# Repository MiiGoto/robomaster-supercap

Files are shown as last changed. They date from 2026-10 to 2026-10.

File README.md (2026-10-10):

# Firmware implementation — 2026-10-08

Current: Rev A STM32G474RET6 firmware source implemented; default SAFE_MONITOR_ONLY. Host logic tests and ARM builds are recorded in [docs/firmware_validation.md](docs/firmware_validation.md). No flash, option-byte write, real PWM/contact actuation or energizing was performed. Hardware/CAD is unchanged. Calibration, control gains, timing, BQ physical behavior and power limits require bench measurement and human review before first flash/energizing.

Current guides: [firmware architecture](docs/firmware_architecture.md), [operation](docs/supercap_user_guide.md), [commissioning](docs/firmware_commissioning.md), [CAN protocol](docs/can_protocol.md), [tuning](docs/control_tuning.md), [flash setup](docs/firmware_flash_setup.md).

## Historical records (preserved)

# PCB routing complete — 2026-10-07

**Current: Prototype Rev A CAD routing complete.** KiCad10.0.6の正式PCBでnative未接続0、全DRC0 errors/0 warnings、schematic parity0、ERC0 errors/0 warningsを確認した。全331ネット／1524 net-assigned pad recordsの物理接続と、設計manifestの1478 pad/net assignmentsを照合済み。これはCAD接続・規則検証であり、製造リリース、通電許可、120 W性能、競技適合の承認ではない。

一般銅箔間隔0.20 mm、承認済み39 ICの同一部品内Pad/Pad0.15 mmを維持した。新たなDRC除外・No ERC・規則緩和はない。未コミットの`.kicad_pro`設定展開は保持し、functional commitに含めない。詳細は[配線完了記録](docs/pcb_routing_completion.md)を現在の情報源とする。以下は過去時点の記録として保存する。

## Historical records (preserved)

# Routing checkpoint — 2026-10-04

**Routing incomplete.** 保存したPCBは電力7ネットの全パッド接続と、局所GND/一部信号配線を追加したcheckpoint。native未接続 **610本**（239 nets）、寸法・間隔DRC **0 errors/0 warnings**、schematic parity0。元の935本から325本を解消したが、配線完成/製造/通電/性能保証は意味しない。

現在の結果と残りを[配線作業記録](docs/pcb_routing_completion.md)で確認する。以下は以前の経緯を含む。

# Clearance approval update — 2026-10-04

39対象ICの内部fine-pitchパッド間0.15 mmをユーザー承認に基づき許容し、その他の銅箔間隔は0.20 mm以上を維持した。DRCの寸法・間隔違反0/0、未接続935本。[検証記録](docs/pcb_rev_a_validation.md)を現状として優先する。以下は変更前の経緯を含む。

# PCB engineering authorized — 2026-10-04

ユーザーがsurge・OC遮断時間・fuse/接触器協調・熱・放電時間の実測前にPCB配置/配線へ進むことを明示承認した。[現行PCB記録](docs/pcb_rev_a.md)を優先する。未実測の項目はPrototype Assumptionとして保持し、製造/通電/性能保証にはしない。以下の「PCB未承認/開始しない」は過去時点の記録として残す。

## Historical records (preserved)

# Prototype Rev A — 2026-10-04 delegated decisions

ユーザーの委任に基づき、セル監視RAM設定・exact passive選定・外部ベンチ遮断アセンブリ・保護/熱/放電検証基準を[現行選定書](docs/rev_a_design_freeze.md)へ確定した。選定はPrototype Assumption、実測検証は未実施。平均cap電流の初期上限9.5 A、OC約12 A、目標遮断0.5 µs、各link bulk6×470 µF、precharge timeout3 s。12 A/120 Wは後続の検証目標として保持。PCB placement/通電は開始しない。以下の2026-10-03以前の未選定表示は経緯記録であり、この選定書が優先する。

# Prototype Rev A — current status

2026-10-03 JST。**Current: Prototype Rev A schematic only.** Task2 architectureはユーザー採用承認済み。実機条件未確認は[Prototype envelope](docs/prototype_rev_a_envelope.md)に明示した **ASSUMPTION — MUST VERIFY ON PROTOTYPE** として隔離し、詳細electrical schematicを作成した。部品/保護閾値はprototype候補で性能保証ではない。[現行review](docs/rev_a_schematic_review.md)と[pinout](docs/pinout.md)が現在の設計記録。PCB placement/routing、firmware、通電、120W使用許可、競技適合、Task4開始は未承認。以下の旧status/approval pending/skeleton-only記述はhistorical recordであり現在statusではない。

[Validation record](docs/rev_a_validation.md): ERC0/0 baseline; current counts in validation record. External assembly and cell-monitor RAM profile are selected; hardware programming/qualification remain unperformed.

## Historical records (preserved)

# Task 4 current status — placement gate未通過

2026-10-03 JST。Task 3 base428ad10を保持。重大TBDと詳細回路未実装のため添付Task 4 §1に従いplacement/outline/footprint/routingは行わない。[独立review](docs/task4_review.md)が現在status、[PCB方針](docs/task4_pcb_strategy.md)は提案、[検査結果](docs/task4_baseline.md)は既存skeleton限定。Task 5へ進まない。以下は過去Task記録。

---

# Task 3 current status

2026-10-03 JST。Task 2案はユーザー採用承認済み。実bus/surge・peak継続/間隔・ambient/coolingは未確定（ユーザー回答：不明）。承認範囲と詳細回路gateは[Task 3 review gate](docs/task3_review_gate.md)を優先する。Task 3は候補評価まで進行中、詳細回路未実装。以下のTask 2承認待ち表示は承認範囲についてhistorical record。

---

# robomaster-supercap — Task 2

2026 RMUL用energy bufferの設計検討。英雄・歩兵・哨兵の競技assistが対象、EngineerはS5搭載許可対象外。Task1成果を保ち、Task2 architecture proposal・simulation・9-page KiCad conceptを追加。完成/検証済み回路ではない。

- [Requirements/status](requirements.md)
- [Architecture and 11 modes](docs/architecture.md)
- [Evidence and selected proposals](docs/task2_decisions.md)
- [Calculation results](simulation/results.md)
- [Safety](docs/safety.md) / [FMEA](docs/fmea.md)

第一案は9S 50F、4-switch bidirectional buck-boost、G474RE/LQFP64、signed high-side shunts、independent fault latch。全選定案はAssumptionとしてhuman review待ち、robot実bus/power/thermalはTBD。stored energyはOFF後も残る。
Roadmap: Task1完了→Task2 reviewable proposal→人間承認→別途Task3 component selection。mainへ自動mergeしない。詳細回路・routing・firmware・hardware testingなし。第三者PDF等は公開対象外、引用linkと出典のみ。

---

## Task 1 record (historical; Task 2 above takes precedence)

# robomaster-supercap

RoboMaster向けスーパーキャパシタ電源システムの要求・安全設計と開発基盤。
robot busの余剰energyを蓄え、必要時にassistし、状態監視とCAN通信を行う。

## Architecture

Robot Power Bus ⇄ Input Protection ⇄ Bidirectional Power Converter ⇄ Supercapacitor Bank。
MCUはbus/bank voltage、current、temperature、faultを監視する。独立保護がgate enableを拒否できる構成を要求する。
競技用の公式管理モジュール・検査経路を含む実接続は適用規則確認後に決める。

## Repository structure

```text
README.md / AGENTS.md / PROJECT_CONTEXT.md
requirements.md / references.md
hardware/kicad/        block-level project skeleton
firmware/controller/  future firmware requirements
simulation/           future model scope
docs/                 architecture, comparison, safety, FMEA, bringup
test/                 verification plan and publication audit
```

## Safety notice

蓄積energyは電源OFF後も残る。短絡・cell過電圧・逆流・熱暴走・connector arcを設計要件として扱う。
このrepositoryは通電可能な完成回路、製造データ、検証済みシステムを提供しない。
KiCad ERCが通っても、部品・netがないskeletonの安全性や動作は証明しない。

## Current status

Task 1文書とKiCad skeleton。詳細power stage、PCB layout、firmware、prototypeは未着手。
Confirmed / Assumption / TBDはPROJECT_CONTEXTとrequirementsに明示。
環境確認は [environment](docs/environment.md)、調査は [comparison](docs/reference_comparison.md)。

## Reference policy

外部設計は設計意図を比較し、[references.md](references.md)へ記録する。
外部回路図・PCB・PDF・画像・コードは取り込まない。ライセンスの衝突・不明点も記録する。
本プロジェクトの公開ライセンス選択はTBD。PUBLICであることだけで再利用許諾とはしない。

## Roadmap

1. Task 1: environment / repository / research / requirements / safety / KiCad skeleton。
2. 人間レビュー: 競技適用、robot仕様、capacitor候補、限界値、topology。
3. 承認後の別Task: 詳細回路、独立保護の検証、制御設計。
4. その後: PCB / firmware / 段階的bringup / fault injection / robot統合。

Task 2は自動開始しない。

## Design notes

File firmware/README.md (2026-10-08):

# Firmware implementation — 2026-10-08

Current: Rev A STM32G474RET6 firmware source implemented; default SAFE_MONITOR_ONLY. Host logic tests and ARM builds are recorded in docs/firmware_validation.md. No flash, option-byte write, real PWM/contact actuation or energizing was performed. Hardware/CAD is unchanged. Calibration, control gains, timing, BQ physical behavior and power limits require bench measurement and human review before first flash/energizing.

Current guides: [firmware architecture](../docs/firmware_architecture.md), [operation](../docs/supercap_user_guide.md), [commissioning](../docs/firmware_commissioning.md), [CAN protocol](../docs/can_protocol.md), [tuning](../docs/control_tuning.md), [flash setup](../docs/firmware_flash_setup.md).

## Historical records (preserved)

# PCB routing complete — 2026-10-07

**Current: Prototype Rev A CAD routing complete.** KiCad10.0.6の正式PCBでnative未接続0、全DRC0 errors/0 warnings、schematic parity0、ERC0 errors/0 warningsを確認した。全331ネット／1524 net-assigned pad recordsの物理接続と、設計manifestの1478 pad/net assignmentsを照合済み。これはCAD接続・規則検証であり、製造リリース、通電許可、120 W性能、競技適合の承認ではない。

一般銅箔間隔0.20 mm、承認済み39 ICの同一部品内Pad/Pad0.15 mmを維持した。新たなDRC除外・No ERC・規則緩和はない。未コミットの`.kicad_pro`設定展開は保持し、functional commitに含めない。詳細は[配線完了記録](../docs/pcb_routing_completion.md)を現在の情報源とする。以下は過去時点の記録として保存する。

## Historical records (preserved)

# PCB engineering authorized — 2026-10-04

ユーザーがsurge・OC遮断時間・fuse/接触器協調・熱・放電時間の実測前にPCB配置/配線へ進むことを明示承認した。[現行PCB記録](../docs/pcb_rev_a.md)を優先する。未実測の項目はPrototype Assumptionとして保持し、製造/通電/性能保証にはしない。以下の「PCB未承認/開始しない」は過去時点の記録として残す。

## Historical records (preserved)

# Prototype Rev A — 2026-10-04 delegated decisions

ユーザーの委任に基づき、セル監視RAM設定・exact passive選定・外部ベンチ遮断アセンブリ・保護/熱/放電検証基準を[現行選定書](../docs/rev_a_design_freeze.md)へ確定した。選定はPrototype Assumption、実測検証は未実施。平均cap電流の初期上限9.5 A、OC約12 A、目標遮断0.5 µs、各link bulk6×470 µF、precharge timeout3 s。12 A/120 Wは後続の検証目標として保持。PCB placement/通電は開始しない。以下の2026-10-03以前の未選定表示は経緯記録であり、この選定書が優先する。

# Firmware status — Prototype Rev A

No firmware implementation. Adopted STM32G474RE/LQFP64 pin allocation and default-off protections are in [pinout](../docs/pinout.md) and [schematic review](../docs/rev_a_schematic_review.md). Future work: HRTIM timing/ADC synchronization, BQ supercap provisioning/readback, watchdog health/CAN lease, control loops, precharge/dump/contact interlocks and fault state machine. BOOT0/NRST options and cell monitor profile must be reviewed before any energizing. Hardware latch protection is not optional. Historical firmware requirements remain in [controller README](controller/README.md).

Cell monitor RAM profile now exists in config/bq76942_rev_a.json;check_cell_profile.py is offline arithmetic only. Firmware has not been implemented or flashed.

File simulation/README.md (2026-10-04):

# Prototype Rev A — 2026-10-04 delegated decisions

ユーザーの委任に基づき、セル監視RAM設定・exact passive選定・外部ベンチ遮断アセンブリ・保護/熱/放電検証基準を[現行選定書](../docs/rev_a_design_freeze.md)へ確定した。選定はPrototype Assumption、実測検証は未実施。平均cap電流の初期上限9.5 A、OC約12 A、目標遮断0.5 µs、各link bulk6×470 µF、precharge timeout3 s。12 A/120 Wは後続の検証目標として保持。PCB placement/通電は開始しない。以下の2026-10-03以前の未選定表示は経緯記録であり、この選定書が優先する。

# Task 2 calculation model

Python standard library only。power_budget.py冒頭のBank/BUS_V/power変数で3 scenariosを変更可能。C/F、V、Ω、A、W、J、sのSI単位。ηはconverterのみ、ESRを別計算。

```text
python simulation/power_budget.py --write-report
python -m unittest discover -s test -p "test_*.py"
```

results.mdは公開用の自作計算結果。runtimeは電流clippingを含みpeak ratingではない。aux/leakage/temperature/loop/transient/thermalモデルを含まず楽観値。SPICE/firmware実装ではない。

---

## Task 1 record (historical; Task 2 above takes precedence)

# Simulation scope

Task 1ではモデル実装なし。将来の検証: bus/cap電圧の上下関係、ESR損失、cellばらつき、precharge、shutdown放電、fault時のbody-diode電流経路。
control-loop compensation、switching frequency最適化は別Task。

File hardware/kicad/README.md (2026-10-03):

# Task 2 same-project update

robomaster_supercap.kicad_proを継続使用。root UUIDと既存sheet UUIDを維持しPRECHARGEを追加、9 concept pages。各sheetにblock interfaceの説明を更新。POWER_STAGEは四switch概念textのみでMOSFET/driver/L部品・netsなし、electrical connectivity未実装。PCB/project設定はTask1から変更なし。
ERC成功はhierarchy読み込み確認のみ。部品ratings/pin/機能/safety検証ではない。

---

## Task 1 record (historical; Task 2 above takes precedence)

# KiCad skeleton

Open `robomaster_supercap.kicad_pro` with KiCad 10.0.6。
rootと7 hierarchy pages: CONTROLLER / POWER_INPUT / SUPERCAP_BANK / POWER_STAGE / SENSING / CAN / SAFETY。
説明textのみ。部品、pin、electrical nets、MOSFET、driver、inductor、connector定格の実装なし。
PCBは空のplaceholder。outline、footprint、track、zoneなし。厚さ等のKiCad defaultは承認済み製造仕様ではない。
ERCはparser/hierarchy確認であり電気安全や配線の検証ではない。空boardのDRCはoutlineがない等の未実装結果をexpected limitationとして記録する。
generatorは新規targetのみ作成し既存fileがあれば拒否。通常編集はKiCadで行い、generator再実行で上書きしない。

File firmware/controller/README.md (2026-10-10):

# Firmware implementation — 2026-10-08

Current: Rev A STM32G474RET6 firmware source implemented; default SAFE_MONITOR_ONLY. Host logic tests and ARM builds are recorded in [docs/firmware_validation.md](../../docs/firmware_validation.md). No flash, option-byte write, real PWM/contact actuation or energizing was performed. Hardware/CAD is unchanged. Calibration, control gains, timing, BQ physical behavior and power limits require bench measurement and human review before first flash/energizing.

Current guides: [firmware architecture](../../docs/firmware_architecture.md), [operation](../../docs/supercap_user_guide.md), [commissioning](../../docs/firmware_commissioning.md), [CAN protocol](../../docs/can_protocol.md), [tuning](../../docs/control_tuning.md), [flash setup](../../docs/firmware_flash_setup.md).

## Build and tests

Project-authored source: Core (HAL adapters), App (portable logic), config (reviewed defaults/profile), tests (host emulator). External unmodified HAL/device/CMSIS versions and licenses: [Drivers/README.md](Drivers/README.md). No automatic downloads, installs, flash or hardware operations exist in build targets.

Host (Linux/WSL GCC or another supported C11 GCC/Clang installation):

```sh
cmake -S firmware/controller -B build/firmware-host
cmake --build build/firmware-host -j 4
ctest --test-dir build/firmware-host --output-on-failure
python -B firmware/controller/tools/generate_bq_profile.py --check
python -B firmware/controller/tools/test_profile.py
```

ARM (set external paths to the pinned sources; Ninja optional):

```sh
cmake -S firmware/controller -B build/firmware-arm -G Ninja \
  -DCMAKE_TOOLCHAIN_FILE=cmake/arm-gcc.cmake \
  -DARM_TOOLCHAIN_BIN=/path/to/arm-tools/bin \
  -DHAL_ROOT=/path/to/hal -DDEVICE_ROOT=/path/to/device -DCMSIS_ROOT=/path/to/cmsis \
  -DFW_MODE=SAFE_MONITOR_ONLY
cmake --build build/firmware-arm -j 4
```

Windows: use `tools/build_windows.ps1` with explicit `-CMake`, `-Ninja`, `-ArmTools`, `-HalRoot`, `-DeviceRoot`, `-CmsisRoot` paths. It uses temporary ASCII junctions because the tested Ninja cannot resolve the Unicode checkout path. It never removes/replaces an existing alias and never moves the checkout. `-Mode` defaults SAFE_MONITOR_ONLY; select a new `-AliasRoot` if an existing alias belongs to another checkout. Output is ELF/HEX/map under the alias build directory, not programmed into a board.

Project code uses -Wall/-Wextra/-Werror; vendor code is separately compiled without -Werror. Host builds execute all three modes with mocked hardware permissions; those test fixtures do not change production default permissions. Optional host sanitizer configuration (tested WSL non-PIE executable, add `-DCMAKE_EXE_LINKER_FLAGS=-no-pie`): `-DCMAKE_C_FLAGS="-fsanitize=address,undefined -fno-omit-frame-pointer -fno-pie"`.

Native connectivity audit: export a local-only KiCad S-expression netlist, then `python -B firmware/controller/tools/check_hardware_contract.py path/to/export.net`. Do not commit native exports containing absolute local paths. The audit checks47 U11 physical assignments plus ADC/AF sentinels; it is not a hardware timing test.

## Historical records (preserved)

# Prototype Rev A — 2026-10-04 delegated decisions

ユーザーの委任に基づき、セル監視RAM設定・exact passive選定・外部ベンチ遮断アセンブリ・保護/熱/放電検証基準を[現行選定書](../../docs/rev_a_design_freeze.md)へ確定した。選定はPrototype Assumption、実測検証は未実施。平均cap電流の初期上限9.5 A、OC約12 A、目標遮断0.5 µs、各link bulk6×470 µF、precharge timeout3 s。12 A/120 Wは後続の検証目標として保持。PCB placement/通電は開始しない。以下の2026-10-03以前の未選定表示は経緯記録であり、この選定書が優先する。

# Prototype Rev A — current status

2026-10-03 JST。**Current: Prototype Rev A schematic only.** Task2 architectureはユーザー採用承認済み。実機条件未確認は[Prototype envelope](../../docs/prototype_rev_a_envelope.md)に明示した **ASSUMPTION — MUST VERIFY ON PROTOTYPE** として隔離し、詳細electrical schematicを作成した。部品/保護閾値はprototype候補で性能保証ではない。[現行review](../../docs/rev_a_schematic_review.md)と[pinout](../../docs/pinout.md)が現在の設計記録。PCB placement/routing、firmware、通電、120W使用許可、競技適合、Task4開始は未承認。以下の旧status/approval pending/skeleton-only記述はhistorical recordであり現在statusではない。

## Historical records (preserved)

# Controller firmware placeholder

実装なし。STM32G4 / F334を比較中。型番・pinout・toolchain projectはTBD。
将来: boot self-test → precharge → charge/standby/assist → fault/shutdown。
PWM同期ADC、current loop、hardware fault inputs、watchdog、CAN timeout、telemetry、calibration管理を分離する。
起動・reset・crashでenable OFF。ISR時間予算と通信処理の分離を検証する。
SWD halt時のPWM継続も危険として扱う。デバッグで保護を無効化しない。

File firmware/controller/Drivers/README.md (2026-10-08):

# External STM32 dependencies

No vendor code is copied into this public repository. Project-authored code is in `Core/`, `App/`, `config/`, `tests/` and `tools/`. No CubeMX-generated files are claimed.

Build-tested source dependencies (unmodified, kept in ignored local storage):

| Dependency | Pinned version / commit | License | CMake setting |
|---|---|---|---|
| [ST G4 HAL](https://github.com/STMicroelectronics/stm32g4xx-hal-driver/tree/v1.2.5) |v1.2.5 / d69997c6dcdc2d672afae31fee03713fb033c4a8|BSD-3-Clause in LICENSE.md|HAL_ROOT|
| [ST G4 CMSIS device](https://github.com/STMicroelectronics/cmsis-device-g4/tree/v1.2.4)|v1.2.4 / f4ee399953e3b5c437788526e93b10efa5fad4fa|Apache-2.0|DEVICE_ROOT|
| [Arm CMSIS core](https://github.com/ARM-software/CMSIS_5/tree/5.9.0)|5.9.0 / 2b7495b8535bdcb306dac29b9ded4cfb679d7e5c|Apache-2.0|CMSIS_ROOT|

An installed STM32CubeG4 package may supply the same directories, but its exact revision must be recorded and rebuilt/reviewed. `CMSIS_ROOT/CMSIS/Core/Include` is the standalone CMSIS layout; for a Cube package point to its corresponding root layout or adjust the include path explicitly. Dependencies are not fetched by CMake. Toolchain installation, board connection and flashing are never build actions.

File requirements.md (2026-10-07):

# PCB routing complete — 2026-10-07

**Current: Prototype Rev A CAD routing complete.** KiCad10.0.6の正式PCBでnative未接続0、全DRC0 errors/0 warnings、schematic parity0、ERC0 errors/0 warningsを確認した。全331ネット／1524 net-assigned pad recordsの物理接続と、設計manifestの1478 pad/net assignmentsを照合済み。これはCAD接続・規則検証であり、製造リリース、通電許可、120 W性能、競技適合の承認ではない。

一般銅箔間隔0.20 mm、承認済み39 ICの同一部品内Pad/Pad0.15 mmを維持した。新たなDRC除外・No ERC・規則緩和はない。未コミットの`.kicad_pro`設定展開は保持し、functional commitに含めない。詳細は[配線完了記録](docs/pcb_routing_completion.md)を現在の情報源とする。以下は過去時点の記録として保存する。

## Historical records (preserved)

# PCB engineering authorized — 2026-10-04

ユーザーがsurge・OC遮断時間・fuse/接触器協調・熱・放電時間の実測前にPCB配置/配線へ進むことを明示承認した。[現行PCB記録](docs/pcb_rev_a.md)を優先する。未実測の項目はPrototype Assumptionとして保持し、製造/通電/性能保証にはしない。以下の「PCB未承認/開始しない」は過去時点の記録として残す。

## Historical records (preserved)

# Prototype Rev A — 2026-10-04 delegated decisions

ユーザーの委任に基づき、セル監視RAM設定・exact passive選定・外部ベンチ遮断アセンブリ・保護/熱/放電検証基準を[現行選定書](docs/rev_a_design_freeze.md)へ確定した。選定はPrototype Assumption、実測検証は未実施。平均cap電流の初期上限9.5 A、OC約12 A、目標遮断0.5 µs、各link bulk6×470 µF、precharge timeout3 s。12 A/120 Wは後続の検証目標として保持。PCB placement/通電は開始しない。以下の2026-10-03以前の未選定表示は経緯記録であり、この選定書が優先する。

# Prototype Rev A — current status

2026-10-03 JST。**Current: Prototype Rev A schematic only.** Task2 architectureはユーザー採用承認済み。実機条件未確認は[Prototype envelope](docs/prototype_rev_a_envelope.md)に明示した **ASSUMPTION — MUST VERIFY ON PROTOTYPE** として隔離し、詳細electrical schematicを作成した。部品/保護閾値はprototype候補で性能保証ではない。[現行review](docs/rev_a_schematic_review.md)と[pinout](docs/pinout.md)が現在の設計記録。PCB placement/routing、firmware、通電、120W使用許可、競技適合、Task4開始は未承認。以下の旧status/approval pending/skeleton-only記述はhistorical recordであり現在statusではない。

## Rev A current requirements register

| Item | Current decision | Status |
|---|---|---|
| Rules |2026 RMUL,prior source editions;event supplement applicability remains open |Confirmed target / eligibility TBD|
| Bank |9S SCCV40B506SRB50F;Ceq5.5556F;rest12–22.05V;cell normal2.45V,COV2.530V |Adopted goals / Prototype selection|
| Bus |22–26V;surge investigation36V,measured VDS<=48V and reviewed SOA |Prototype Assumption / waveform TBD|
| Power/current |40W charge,80/120W assist requests;normal8A,initial peak-average9.5A;12A future goal |Adopted goals / capability TBD|
| Converter/MCU |Four-switch bidirectional buck-boost,G474RE/LQFP64,200kHz/22uH |Approved architecture / schematic only|
| Sensing/OC |Three3mR WSK2512 Kelvin,INA240 signed,INA293/TLV3202;cap/IL~12A;0.5us clearing required |Concrete schematic / actual response TBD|
| Cell monitor |BQ7694204,39-entryRAM profile,SPI CRC,9S0x02FF,COV/CUV,active-low-fault permits,host-only trim |Selected configuration / NOT programmed|
| Link/precharge |Each6×EEUFR1J471,100R HS25+AQZ202G,NO AEV bypass,3s timeout |Prototype selection / inrush test TBD|
| Discharge |10k bleed,100R HS25 dump/service;40min to1V target pluscell/rebound/energy checks |Procedure target / measured time TBD|
| External isolation |FourAEV14012,DDR-60L-12,MINI99758V fuses+0FHM holders;manual disconnect |Bench assembly selected / interruption coordination test TBD|

Confirmed means adopted target or checked fact; **does not mean demonstrated capability**. Full-power gates remain surge/regen/source impedance, duty, heat, OC clearing, residual energy and isolation fault capability. Current MCU allocation is docs/pinout.md, overriding historical spare-count/pin plans.

## Historical records (preserved)

# Task 4 current status — placement gate未通過

2026-10-03 JST。Task 3 base428ad10を保持。重大TBDと詳細回路未実装のため添付Task 4 §1に従いplacement/outline/footprint/routingは行わない。[独立review](docs/task4_review.md)が現在status、[PCB方針](docs/task4_pcb_strategy.md)は提案、[検査結果](docs/task4_baseline.md)は既存skeleton限定。Task 5へ進まない。以下は過去Task記録。

---

# Task 3 current status

2026-10-03 JST。Task 2案はユーザー採用承認済み。実bus/surge・peak継続/間隔・ambient/coolingは未確定（ユーザー回答：不明）。承認範囲と詳細回路gateは[Task 3 review gate](docs/task3_review_gate.md)を優先する。Task 3は候補評価まで進行中、詳細回路未実装。以下のTask 2承認待ち表示は承認範囲についてhistorical record。

---

# Task 2 requirements freeze — proposal, not construction approval

2026-10-03 JST。[採用理由・一次根拠・margin](docs/task2_decisions.md)、[計算](simulation/results.md)。Confirmedは実装完了を意味しない。Assumptionは人間レビュー待ち。

| Item | Current value / decision | Status | Remaining evidence |
|---|---|---|---|
| Ruleset | 2026 RMUL、哨兵/歩兵/英雄/エンジニアの要求 | Confirmed | 開催地/種目/補足TBD |
| Rule editions | RMUL CN V1.2.0 / 制作CN V1.3.0、公式RMULアーカイブ掲載最新版 | Confirmed | 会場答疑確認 |
| Eligibility | 底盤assist bankは英雄/歩兵/哨兵のみ、Engineer対象外(S5) | Confirmed | Engineerへの別用途は許可を推測しない |
| Supply maximum | 対象4種30 V、power management input22–26 V | Confirmed | converter実端のdroop/surgeはTBD |
| Vbus range | 計算22/24/26 V; 実operating min/nom/max | Assumption / TBD | battery型番、Chassis端波形、regen |
| Rule energy | nominal2000 J / measured2200 J | Confirmed | capacityはrated voltageで計算、実測検査 |
| Power constraint | 3V3 Hero/Sentry100 W, Infantry90/75 W; Infantry Match120 W | Confirmed | 種目/型選択、referee計測点の統合 |
| Cell count / product | SCCV40B506SRB、9S第一案; alternatives7S HV60 /4S HV100 | Assumption | thermal/stock/mount/人間承認 |
| Capacitance | cell50 F, Ceq5.5556 F nominal、tol−10/+30% | Assumption | 製品採用・実測・aging |
| Vcap range | useful12..22.05 V; nominal比較18 V; cell normal2.45 V | Assumption | 精度/balance/overshoot配賦の実証 |
| Cell rating | 選定候補datasheet2.7 V/cell, rated sum24.3 V | Confirmed (candidate) | normal定格と混同しない |
| Energy | A usable950.5625 J nominal; rated1640.25 J; +30%2132.325 J | Confirmed calculation under Assumption | 実効C/セル差/検査測定 |
| Charge current / power | bus input40 W scenario、normal cap clamp8 A | Assumption | 実charge max/TBD、referee負荷budget |
| Discharge current | normal8 A / peak12 A scenario; module peak/continuous15 A rule | Assumption / Confirmed rule | ripple/error/trip overshoot、熱定格TBD |
| Nominal / peak power | request80 /120 W、current/thermal/UVでderate | Assumption | 実max、peak duration、robot要求TBD |
| Converter | 4-switch non-inverting bidirectional synchronous buck-boost | Assumption selected proposal | 重なり電圧・制御・loss・人間承認 |
| Switching / L | 100–200 kHz; exploration11–22 µH, ΔI3 A p-p | Assumption | 全corner/duty/部品/温度で再算出 |
| MCU | STM32G474RE LQFP64; alternative G431RB | Assumption selected proposal | package AF conflict、errata、承認 |
| Current sensing | bus/cap high-side signed shunts + separate inductor sense | Assumption selected proposal | amplifier settling/共通故障/承認 |
| Voltage sensing | bus/bank ADC + differential per-cell monitor、独立OV | Confirmed requirement / Assumption method | tap protection/range/error |
| Temperature | MOSFET群/inductor/bank各代表1点NTC | Assumption | hotspot測定、thresholdsTBD |
| Balancing | IC-based switched passive、MCU非依存OV inhibit | Assumption selected proposal | IC/精度/損失/供給断時動作 |
| Precharge | resistor path + normally-OFF bypass、ΔV/current/time確認 | Assumption selected proposal | R/Clink/energy/start time/approval |
| Discharge | permanent bleed + controlled dump + service tool +独立表示 | Assumption selected proposal | Vsafe/Esafe/time/公式検査との共存TBD |
| Hardware protection | external OC/OV/latch/watchdog/kill、reset/float OFF | Confirmed requirement | clearing時間/回路/故障遮断能力TBD |
| CAN | telemetry使用、official module→CAN1、Classic CAN互換を想定 | Confirmed requirement / Assumption format | bitrate/ID/period/timeout/TBD |
| Mechanical / cooling | port1つ、検査lead≥100 mm、mount/冷却/絶縁 | Confirmed rule / TBD dimensions | robot envelope/thermal approval |
| Debug / test / firmware | SWD/UART、ADC同期、state machine、fault injection計画 | Confirmed requirement | implementation、試験は今回なし |
| Expansion | spare GPIO4、cell monitor interface | Assumption | pin plan/area |

Task 3へ進む前のhuman review: cell数/Vcap、max current/peak power、topology、MCU、sensing、prechargeと全power component定格。実robot仕様不明のため最終数値freezeではなく、証拠付きproposal freeze。Task 3自動開始禁止。

---

## Task 1 record (historical; Task 2 above takes precedence)

# Requirements register

2026-10-03 JST。Confirmed = 依頼から確定した要求または直接確認した資料の内容。
Assumption = 比較に使う仮定。TBD = 未決定。要求のConfirmedは実装・検証の完了を意味しない。

## Competition constraints: current applicability is TBD

公式 [Rules/Resources Hub](https://bbs.robomaster.com/wiki/20204847) と [downloads](https://www.robomaster.com/zh-CN/resource/download/competition) を確認。
取得できた一次資料は **2026制作規則 V1.3.0 (2026-02-09)**。以下はその版の内容としてConfirmed。
現在適用する最新版・大会・地域・robot種別はTBDであり、下記数値を本設計の確定限界値にしない。

[公式V1.3.0 PDF](https://bbs-web-static.robomaster.com/715e2519e5384666a5d13edda17c6b831770696773838/RoboMaster%202026%20%E6%9C%BA%E7%94%B2%E5%A4%A7%E5%B8%88%E9%AB%98%E6%A0%A1%E7%B3%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)

| 条項 / 印刷page | 確認した版での内容 | 本projectへの適用 |
|---|---|---|
| S5 / 14 | Hero / Infantry / Sentryのみ、各robot最大1組 | TBD |
| S6 / 14 | nominal energy合計 ≤2000 J、measured energy合計 ≤2200 J。nominal計算は耐圧と容量による1/2 C U² | TBD、動作電圧でnominalを過小評価しない |
| S7 / 14 | Chassisに接続し底盤powerに寄与しないcapacitorのnominal容量合計 ≤10 mF | TBD、通常bus decouplingも分類確認 |
| 3.12 / 97–98 | bankと自作power control boardの間に公式管理module、module CANはpower management CAN1へ | TBD、独自telemetry CANと混同しない |
| S184 / 98 | 公式moduleのXT30接口はpeak / continuousとも ≤15 A | TBD、bus側current限界とは同義でない |
| S185–189 / 98 | 検査時bankを満充電から1 V未満まで測定、検査lead ≥100 mm、moduleにアクセス可能、bank power接口は1つ | TBD、1 Vを一般のservice-safe閾値としない |

第三者indexにはV2.0.0制作規則(2026-06-26)とV2.2.0競技規則(2026-08-07)、2027先行資料への案内があった。
一次資料としての最新版取得・版照合はできず、第三者PDF linkは404。探索はここで停止した。
対象大会を決め、公式hubから最新版と補足を取得し、上表の変更差分・接続図・chassis power計測点を人間レビューする。
最大bus電圧・許容powerは今回一次資料で対象robotに対して確定できていない。過去の24 V / 240 W等を流用しない。

## Requirements

| ID | Category | Requirement | Status | Acceptance / next evidence |
|---|---|---|---|---|
| COMP-01 | Competition constraints | 大会・年・地域・robot種別・最新規則・裁判systemを特定 | TBD | 版/date/条項/適用範囲をレビュー署名 |
| COMP-02 | Competition constraints | 公式管理module・検査path・single bank接口を満たす | TBD | 適用図面と接続を照合 |
| IN-01 | Electrical input | bus min/nominal/max、surge、source impedance、regen吸収能力 | TBD | robot power仕様と測定 |
| IN-02 | Electrical input | reverse polarity、inrush、busへの逆流を制限 | Confirmed | approved limitsでfault test |
| OUT-01 | Electrical output | assist power/current/duration、ripple、response time | TBD | robot load profile / competition制約 |
| ES-01 | Energy storage | cell数/製品/C/ESR/voltage/usable energy/agingを決定 | TBD | maker datasheetとworst case計算 |
| ES-02 | Energy storage | series cell imbalanceを検出し弱いcellを保護 | Confirmed | bank正常でもcell OVならcharge inhibit |
| CHG-01 | Charge control | current/power/voltage上限を守りsoft startする | Confirmed | 上限値TBD、independent trip検証 |
| CHG-02 | Charge control | referee計測点でpower budgetを守る | TBD | power budget loss/delay余裕を承認 |
| DIS-01 | Discharge control | bus電圧、bank/cell UV、熱、currentからassistを制限 | Confirmed | approved envelope外はinhibit |
| DIS-02 | Discharge control | charge↔assistはzero-current確認を経由 | Confirmed | reversal transientを検証 |
| VS-01 | Voltage sensing | busとbankを測定、ADC open/short/saturation/stuck診断 | Confirmed | calibrated測定とfault injection |
| VS-02 | Voltage sensing | per-cell監視方式とindependent OV path | TBD | 共通原因故障をレビュー |
| CS-01 | Current sensing | signed bus/bank/inductor電流の必要測定点を決定 | TBD | topologyとloop帯域から選択 |
| CS-02 | Current sensing | calibrationと独立fast overcurrent trip | Confirmed | sensor故障でも危険電流を止める |
| TS-01 | Temperature sensing | MOSFET/inductor/bankのriskから測定点選定 | Confirmed | hotspot熱測定、断線診断 |
| TS-02 | Temperature sensing | sensor数、derating/trip温度と応答 | TBD | datasheetとthermal model |
| COM-01 | Communication | CANによるmode/fault/voltage/current/energy/temp telemetry | Confirmed | protocol/ID/bitrate/periodはTBD |
| COM-02 | Communication | timeout、bus-off、stale commandはassist/chargeを無効化 | Confirmed | CAN lossと復帰時再arm検証 |
| SAF-01 | Safety | float/reset/crash/aux lossのdefault enable OFF | Confirmed | MCU不要のhardware inhibit確認 |
| SAF-02 | Safety | MOSFET短絡でもenergy fault pathを遮断/制限 | Confirmed | PWM OFFだけで合格しない |
| SAF-03 | Safety | OV/OC/UV/thermal、precharge timeout、reverse current保護 | Confirmed | thresholds / trip latency TBD |
| SAF-04 | Safety | shutdown後の放電、独立電圧確認、再上昇確認 | Confirmed | safe voltage/energy/time TBD |
| MECH-01 | Mechanical | vibration/impact、cell retention、絶縁、touch/arc防護 | Confirmed | enclosure/interfaceレビュー |
| MECH-02 | Mechanical | size/mass、mount、connector、serviceアクセス | TBD | robot envelopeと規則 |
| COOL-01 | Cooling | ESR/semiconductor/inductor/PCB損失の熱経路確保 | Confirmed | ambient/airflow/limits TBD |
| DBG-01 | Debug | SWD/UARTとfault log、halt時に安全停止 | Confirmed | debugger halt fault test |
| TEST-01 | Testability | sense/fault/enable測定点、current-limited初期試験 | Confirmed | bringup checklist |
| FW-01 | Firmware | 明示state machine、watchdog、latched fault、再arm | Confirmed | implementationは別Task |
| FW-02 | Firmware | ADC/PWM同期、ISR予算、calibration integrity | Confirmed | timing / checksum試験 |
| EXP-01 | Future expansion | balancing・telemetry拡張余地を比較 | Assumption | pin/area/cost予算承認 |

## Values requiring human approval

maximum bus voltage、capacitor maximum voltage、cell count、charge/discharge current、output power、topology、MOSFET/inductor/fuse/connector定格は全てTBD。
安全要求の存在は確定していても、数値・回路実現・検証は未確定。

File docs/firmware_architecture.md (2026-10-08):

# Rev A firmware architecture — 2026-10-08

Project-authored C11, HAL peripheral adapters, no RTOS or runtime allocation. Hardware remains unchanged. Routing-complete base: `f38ec4f`. Board U11 pin/net assignments were read from the native KiCad netlist; PC5 REFEREE_PERMIT is additionally implemented. Exact package pins are in `pinout.md`; board GPIO grouping and ADC rank lists are in `Core/Src/board.c`.

## Ownership / scheduling

|Layer|Responsibility|
|---|---|
|External protection + HRTIM FLT1|Asynchronous inactive PWM before ISR; cannot be overridden by a command|
|ADC2 DMA ISR|Latest signed IL, independent software instantaneous guard, PI/duty update; no SPI/CAN/printf/heap|
|ADC1 DMA ISR|Publish latest six-channel scan; foreground conversion|
|Main loop|BQ SPI, conversion, supervisor, CAN parser/telemetry, UART, log, watchdog heartbeat|
|Board safety adapter|Second runtime output veto and default-safe GPIO; short critical sections publish ISR demand/snapshots|

HSI16 PLL gives170 MHz CPU/HRTIM; ADC42.5 MHz. HRTIM master period27200 at×32 gives200 kHz, A/B complementary outputs with provisional deadtime34 fDTG ticks, preload and inactive fault levels. ADC trigger compare6800 is adjustable. ADC1 ranks: CH1 BUS_V,CH2 CAP_V,CH6 TEMP_FET,CH7 TEMP_L,CH8 TEMP_BANK,CH9 BUS_RAW. ADC2 ranks: CH3 IL,CH17 BUS_I,CH13 CAP_I,CH5 CAP_RAW. HAL rank enums are explicit, not assumed arithmetically contiguous. ADC1 circular96 halfword buffer reduces callback rate; ADC2 circular8 halfwords supplies one four-channel frame per half/full callback. Buffers reside in contiguous SRAM, not CCM.

SPI2 mode0/CRC uses~664 kHz; USART2 115200/8N1 interrupt RX/TX; FDCAN1 Classic500 kbit/s. HRTIM timers/ADC triggers may run for sensing in SAFE, but PWM pins remain GPIO LOW and waveform output start is not reachable. Startup sets output latches LOW before configuring output modes. CS and CAN standby start HIGH. CAN standby later becomes LOW for diagnostics.

External heartbeat toggles PB1 only after a completed foreground iteration, about50 ms; IWDG timeout is~1 s nominal LSI. No timer perpetually feeds the watchdog while foreground is stalled. Reset cause is recorded; reset never resumes a power session. HardFault/error handlers stop requests and await watchdog reset. Debug halt is not a safe operating state.

## Allowed transitions

All states may enter FAULT_LATCHED on a fault. Other unlisted transitions are rejected.

|From|To|Gate / condition|
|---|---|---|
|BOOT_SAFE|MONITOR_INIT|All actuators OFF|
|MONITOR_INIT|SELF_TEST|Profile configured/readback, healthy measurements; timeout fails|
|SELF_TEST|DISARMED|Self-test PASS; never auto-ARM|
|DISARMED|PRECHARGE|Explicit ARM + reviewed mode/calibration/tuning/permissions|
|DISARMED|SELF_TEST / SERVICE|Explicit reviewed command/path; dump default forbidden|
|PRECHARGE|READY|BothlinkΔV<1 V stable, bypass settles, resistor paths removed within3 s|
|PRECHARGE|SHUTDOWN|DISARM/SHUTDOWN|
|READY / STANDBY|CHARGE / ASSIST / STANDBY / SHUTDOWN|Fresh command and hardware/sensor permissions|
|CHARGE / ASSIST|STANDBY / SHUTDOWN|No direct direction reversal|
|SHUTDOWN|DISARMED / COOLDOWN / SERVICE|Gate OFF first; bounded zero-current observation; outputs OFF|
|COOLDOWN / FAULT_LATCHED|SELF_TEST|Cause absent, cooled, explicit REARM; then fresh ARM|
|SERVICE|DISARMED|Explicit exit; meter confirmation independent of software|

`app_transition` checks graph legality; `app_command`, `app_live_faults` and `app_safe_outputs` apply permissions/limits. Reserved PRE/BYP/ISO feedbacks are diagnostic samples only; voltage/current/time are used for sequence acceptance. Requests are not measured contact positions.

## BQ7694204

`firmware/config/bq76942_rev_a.json` generates39 RAM entries through `tools/generate_bq_profile.py`; check mode detects stale data. CRC-8 SPI transport verifies replies/echoes with bounded retries, data-memory checksum/length and full readback. Startup confirms device0x7694, enters CONFIG_UPDATE, programs RAM, verifies every entry, exits configuration, observes measurements and periodic open-wire check, checks safety/FET permissions, and publishes MON_CONFIG_VALID last. No OTP or FET test commands exist. Manufacturing FET_EN is read before any conditional toggle, verified after; ALL_FETS_ON follows configuration/safety checks as the existing profile requires.

Logical cells0..8 map to physical channels1..8,10 (mask0x02FF), not channel9. DCHG/DDSG logical fault bits and their physical polarity must be tested with a cell simulator. COW_CHK reports a running open-wire check, not a separate proof that all taps passed. Startup observes a cycle and evaluates measurements/safety; actual tap-disconnect coverage requires bench verification. POR is sticky and not a reliable new-reset counter; mode/status, rotated readback and physical permission loss provide additional detection. BQ failure clears config validity and inhibits power; no blind automatic recovery.

Host balancing: converter OFF, valid cells, bank0–40 C, cells≥2.3 V, startΔ20 mV/stopΔ10 mV policy, one cell, ≤1 s pulse,250 ms settle then remeasure. Measurement validity/PD2 drop during a pulse/settle; this is permitted only in disarmed/service, never a powered session. Independent OV remains active; balancing is not protection.

## Control / faults / calibration

Inner signed IL PI has feedforward duty and anti-windup. Slow power-to-current supervisor applies cell/voltage/thermal/current/peak limits. Initial gains and assumed efficiency are unvalidated; current PI and measured power behavior need bench tuning. Software cap target9.5 A does not replace external~12 A OC. Fault timestamp, first state/sensor snapshot, additional bitmask and frozen64-entry RAM history are retained until reset. No high-frequency Flash logging.

Default calibration gains reflect actual divider/shunt/NTC loading but validity=false; version/CRC detects corruption, not measurement accuracy. Factory defaults plus explicit reviewed flags are used; no in-field flash storage/update. ISR owns its PI context; foreground publishes demands in short interrupt-masked sections, and ISR publishes raw samples/fault flags. Maximum IRQ cycles are tracked, with a secondary period-overrun guard. Timing, sampling and filter delay remain bench items.

Sources: [TI BQ76942 TRM SLUUBY1B](https://www.ti.com/lit/ug/sluuby1b/sluuby1b.pdf), [ST RM0440](https://www.st.com/resource/en/reference_manual/dm00355726.pdf), [ST HAL/LL UM2570](https://www.st.com/resource/en/user_manual/um2570-description-of-stm32g4-hal-and-lowlayer-drivers--stmicroelectronics.pdf). Vendor source versions/licenses are in `firmware/controller/Drivers/README.md`.

ALERT PC11 is polled to request immediate cause-register scanning; an ALERT level alone is not classified as a specific fault. Six reserved feedback levels and ALERT/referee/IRQ-cycle diagnostics are available on telemetry page12. SERVICE dump requires the same monitor/hardware permissions, freshness and a provisional40 min timeout; DISARM exits SERVICE.

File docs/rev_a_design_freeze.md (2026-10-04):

# PCB engineering authorized — 2026-10-04

ユーザーがsurge・OC遮断時間・fuse/接触器協調・熱・放電時間の実測前にPCB配置/配線へ進むことを明示承認した。[現行PCB記録](pcb_rev_a.md)を優先する。未実測の項目はPrototype Assumptionとして保持し、製造/通電/性能保証にはしない。以下の「PCB未承認/開始しない」は過去時点の記録として残す。

## Historical records (preserved)

# Prototype Rev A — delegated design selections

2026-10-04 JST. The user delegated the remaining IC settings, external assembly, exact passives/lands and validation targets. These engineering selections supersede earlier **selection awaiting human decision** entries. They do not constitute measured results, purchase authorization, a fabrication release or permission to energize. **ASSUMPTION — MUST VERIFY ON PROTOTYPE.** PCB placement remains outside this task.

## Selected envelope and acceptance criteria

| Item | Rev A decision | Acceptance / consequence |
|---|---|---|
| Bus |22–26 V,24 V nominal; startup inhibit outside range; no accepted regenerative mode |Record converter-terminal voltage and source impedance; no referee bypass |
| Surge |Investigate36 V upstream events; SMBJ28A is not a36 V clamp; its rated clamp is45.4 V at its specified test current |At actual prototype source/cable/transient energy, protected rail<=45.4 V,FET VDS peak<=48 V,VGS inside datasheet limits and SOA; no repetitive avalanche. A failed test requires clamp/source protection redesign,not a wider undocumented assumption |
| Bank |Nine KEMET SCCV40B506SRB,50 F/2.7 V each;normal cell ceiling2.45 V;bank rest12–22.05 V |Ceq5.5556 F;effective C/ESR,imbalance and actual current/temperature characterized; exact product choice is a prototype selection |
| Energy |Nominal ideal useful950.5625 J;max stored1755.73125 J with+30%C |Usable output is lower after ESR and converter loss;cell limits can reduce window |
| Power |40 W converter charge input;80 W nominal/120 W peak assist requests |Reserve actuator/aux power separately: planning charge-point total<=71 W;does not establish a rule allowance |
| Current |8 A normal average;initial cap average maximum9.5 A;12 A goal retained for later verified envelope |At12 V rest model delivers about87.98 W under9.5 A clamp;120 W remains a request,not a guaranteed output |
| OC |Cap and IL nominal11.991 A with35.7k/10k at3.288 V;bus about7.98 A with58.7k/10k |Provisional aggregate error allowance±7%;**required** complete clearing<=0.5 us for48 V/14.08 uH corner. Arithmetic peak14.535 A. This demanding requirement is unproved; if unattainable,redesign fast sense/kill or reduce threshold/current. No ADC polling substitute |
| Switching |200 kHz primary,180–200 kHz exploration;22 uH XAL1510-223MED |Verify L>=14.08 uH through15 A at temperature and ripple before using OC excursion calculation;deadtime/refresh remain waveform tuning parameters |
| Pulse |Initial design scenario1 s,minimum30 s repetition;software cap current9.5 A |Only after low-energy characterization;temperature and electrical limits override timer |
| Thermal |Calculation25°C;operating test envelope ambient<=40°C,open bench,no credited forced air |Software stop FET/L65°C,bank50°C;warnings60/45°C;hardware backup~69.5/53.7°C. Cooldown below50/40°C plus explicit rearm. Verify junction<100°C,winding<90°C,bank<55°C,connectors<60°C including sensor lag. These are design targets,not measured temperatures |
| Precharge |100 Ω±1% HS25 100R F and AQZ202G per link;normally-open AEV bypass |Each link2820 uF bulk plus ceramics;worst t95~1.03 s;3 s timeout,delta-V<1 V and plausible voltage progression before bypass. Not whole-bank resistor charging |
| Discharge |10kΩ1W permanent bleed;100Ω±1% HS25 switched dump and separate service tool |Worst+30%C ideal~37.61 min to1 V;selected test acceptance<=40 min. With auxiliary failure,use independent tool,not a timing claim |
| Service condition |Bank/both local links<1 V,every cell magnitude<0.5 V,total residual energy<4 J,2 min rebound observation |Verify with independent meter after source disconnect. LED dark and OFF do not prove this condition. Failure keeps service access inhibited |

Sources for engineering facts are the [manufacturer register/reference list](../references.md); [new calculations](../simulation/rev_a_limits_results.md) are original arithmetic. Design limits above are deliberately below cell2.7 V/MOSFET60 V absolute ratings;margin only becomes meaningful after error,ringing and heat are measured.

## Cell monitor configuration

The complete **39-entry RAM-only** selection is [bq76942_rev_a.json](../firmware/config/bq76942_rev_a.json), audited by [offline checker](../tools/check_cell_profile.py). It is not MCU firmware and has not been written to hardware. Use SPI CRC;REG1=3.3 V;9S mask0x02FF (cells1–8+10);COV code50=>2.530 V,CUV24=>1.2144 V;delay code1=>about10 ms;hysteresis101.2 mV. Enable COV/CUV and monitor internal OT80°C;all main current protections remain on independent external hardware because SRP/SRN are grounded.

DCHG/DDSG config0xA6 means **active-low fault,healthy-high permission**,REG1 high drive and pulldown. It is not active-high fault. CHG protection A0x18 and DSG protection A0xE4 follow TI's fast-output mapping guidance;other masks use internal OT. FET_CTRL_EN remains set for logical outputs,charge pump disabled and CP1 tied BAT per the low-side application note;FET_INIT_OFF forces initial permission off. Readback and cell-simulator fault tests precede MON_CONFIG_VALID/ARM. Disable SLEEP for predictable monitoring;repeat RAM provisioning after every reset. No OTP programming,blind FET_ENABLE toggle or FET test command is permitted by this profile.

Open-wire check interval1 s;test every tap disconnect at commissioning and log actual latency. Alarm pin active-low/open-drain with external REG1 pullup. TS pins are unused;external bank NTC hardware is the real bank thermal protection. PF/chemical-fuse engine is not enabled in this prototype profile;the existing external latched shutdown remains mandatory. Configuration mismatch,CRC failure,monitor power loss or failed tap test inhibits operation.

Host-only internal switched-passive balancing:one cell at a time,1 s maximum command,converter disabled,all readings valid,bank0–40°C,cells>=2.3 V,start difference20 mV,stop10 mV. Ten source-side1kΩ1W resistors physically at electrodes plus ten onboard1kΩ1W input resistors protect the tap harness. A single source resistor at24.3 V dissipates at most0.591 W in the simplified short model. This arrangement allows only slow trim (~0.6 mA ignoring switch resistance),not correction during full40 W charge. Large imbalance stops charge and requires separate low-current commissioning;empty-bank startup is not the normal mode. Measurement/open-wire/balancing settling through2kΩ per tap must be tested;do not infer protection from bank voltage alone.

Primary sources: [BQ76942 TRM](https://www.ti.com/lit/ug/sluuby1b/sluuby1b.pdf), [low-side output configuration](https://www.ti.com/lit/an/sluaa84a/sluaa84a.pdf), [TI fast-output mapping FAQ](https://e2e.ti.com/support/power-management-group/power-management/f/power-management-forum/1237508/faq-bq76952-do-the-dchg-and-ddsg-signals-on-the-bq769x2-follow-th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).

## External bench assembly / power / fuses

Four Panasonic AEV14012 contactors:BUS_ISO,CAP_ISO,BYP_BUS,BYP_CAP. Their logical contact-symbol COM/NO/COIL pins are assembly terminals,not manufacturer's housing numbering. Observe manufacturer's polarity and tightening instructions. Product is NRND;existing stock only,approximately1.6 kg total contactor mass. This selects a bench prototype assembly,not a robot-ready mechanical design. Their minimum rated load1 A/12 V prevents relying on them for0.26 A precharge;two AQZ202G AC/DC PhotoMOS devices handle that path. AQZ physical1=LED−,2=LED+,3/4=AC/DC load;external module wiring follows these numbers. LED150Ω from3.3 V with BC847B low-side driver,base1.5kΩ and pulldown;input current/turn-off must be measured.

MEAN WELL DDR-60L-12 supplies actuator12 V on a separate bus branch after the referee measurement/cutoff boundary. Physical terminals1/2=−Vo,3/4=+Vo,5=+Vin,6=−Vin;output− is intentionally bonded systemGND. At22–26 V input apply manufacturer's low-input output derating;reserve24 W output,do not use full60 W nameplate. Four coil maximum planning current1.553 A;gate-driver LM5164 rail does not carry this load. Include input inrush (datasheet20 A at48 V) in source and5 A fuse tests;its duration atactual24 V is unknown. Both actuator under/overvoltage windows inhibit hardware permits (nominal~11.0/13.64 V). Switching supplies can fail,so manual upstream disconnect remains required.

Use Littelfuse MINI997 58 V fuses:0997010.WXN10 A bus,0997015.WXN15 A bank,0997005.WXN5 A actuator. Each in0FHM0002ZXJM58 V waterproof MINI holder;crimp/solder/harness temperatures and holder voltage/current rating checked before assembly. ATOF is32 V and the previous58 V ATOF label is superseded. MINI997 interrupt specification1000 A at58 V is a **component rating**,not assembled interruption proof. Initial qualification condition:measured prospective current<=500 A at<=26 V;use current-limited source before high-energy tests. Typical melting I²t93/270/25 A²s is not guaranteed maximum clearing I²t;do not claim coordination with semiconductor SOA until actual clear-time/let-through and cable withstand are known. Initial harness selection:short2.5 mm² copper power conductors,insulation>=100 V/105°C,documented crimps,with measured connection temperatures;wire product/order availability remains procurement review rather than fabricated evidence.

SMBJ18CA bidirectional suppression across each contactor coil replaces the slow freewheel diode.12 V plus rated clamp29.2 V suggests41.2 V drain stress in that simplified pulse model;measure actual coil current,release and VDS. Require contact opening<=50 ms including suppressor in qualification;AEV datasheet30 ms release excludes protective components. Gate kill handles fast faults;contacts/fuses contain persistent failures. For shorted FET,local shoot-through,welded contact or dead auxiliary supply,verify both healthy isolation contacts andmanual source/bank disconnect;no firmware command or PWM OFF constitutes physical isolation.

Precharge/dump/service resistors:HS25 100R F mounted with thermal compound to a dedicated external aluminum plate at least250x120x3 mm (~600 cm² two faces);verify mounting surface and measured hotspot<80°C for prototype service.25 W requires proper heatsink mounting;maximum design dissipation here about6.83 W at26 V/R−1%,not a pulse-rating certification. Bodies/wiring guarded against touch. Service tool includes its own meter,100Ω HS25 and Blue Sea6006 maintained disconnect;it is independent of MCU/bus auxiliary power. Source and bank manual disconnects also use6006 (48 VDC device,25 A switching listing;300 A continuous listing is not an interrupt rating). Never manually break prospective fault current;fuse/source containment must first remove it. The external schematic shows all three manual paths. Select Alpha Wire5859 PTFE14AWG red/black for short bench power wiring (replaces generic2.5mm² proposal above;14AWG≈2.08mm²),with covered bolted lugs and measured<60°C joints. Manufacturer wire specification lists600 VRMS/200°C but this does not establish a bundled harness current rating. Its mechanical terminations and switching/interrupt behavior must be inspected/tested before use.

## Exact passive selections and footprints

Every generated passive has an **MPN property** and appears in [connectivity/BOM manifest](../simulation/rev_a_connectivity.json). [Ordering map](../tools/rev_a_passives.py) selects Vishay CRCW e3 1% resistors (0805 general,0603 gate,2512 1W),KEMET/Murata ceramics and EEUFR1J471 bulk.0Ω options are actual jumper SKUs;DNI snubbers/turn-off options remain tuning parts,not missing mandatory safety. Part-number generation uses manufacturer ordering syntax;each exact ordering suffix/stock must be checked at procurement. This is a selection list,not an assertion every SKU is currently available.

| Device / passive | Selected mechanical / land decision | Check |
|---|---|---|
| EEUFR1J471 x6/link |12.5 mm diameter,25 mm height,5 mm pitch;CP_Radial_D12.5mm_P5.00mm |63 V,470 uF±20%,1995 mArms100kHz;parallel sharing/ripple/hotspot test required |
| GRM32ER72A225KA35L |1210 nominal3.2x2.5 mm;C_1210_3225Metric |2.2 uF100 V X7R;DC-bias effectiveC not nominal |
| C1210C226K3RACTU |1210;C_1210_3225Metric |22 uF25 V aux output;effective C/loop stability test |
| GRM21BR71H474KA88L |0805 nominal2.0x1.25 mm;C_0805_2012Metric |470 nF50 V bootstrap;effective>=200 nF target |
| Other ceramics |0805 KEMET/Murata MPN map,50/100 V small capacitors;4.7 uF16 V local MCU |Pad geometry consistent with selected size;bias/height/process tolerances remain assembly review |
| WSK25123L000FEA |6.35x3.18 mm body;**terminal T2.21 mm** four-terminal library land |Corrected fromT1.19 (>=5 mΩ version);pad1/4 power,2/3Kelvin;not just a pad-count match |
| MOSFET / driver / MCU |VSONP5x6 / DRC3x3 EP / LQFP64 10x10 pitch0.5 |Original pin aliases and exact lands in pinout;thermal copper and assembly orientation require PCB-stage review |
| BQ76942 |PFB TQFP48 7x7 pitch0.5 |9S physical tap mapping and profile jointly checked;no footprint placement |
| External bank/HS25/contactors/SSR/DDR/fuses |External assembly:deliberately no PCB footprint |Not missing onboard lands;physical housing drawing/source wiring must be inspected before construction |

Other original IC pin/pad mappings remain [pinout](pinout.md). NTC probes use2.54 mm interface headers as external probe connections,not a claim that the bead thermistor body is a header. All pad sets are audited against actual KiCad export. This does not establish paste-mask,assembly clearances,thermal geometry or complete fabrication readiness.

## Completion boundary

Engineering choices/profile/schematic/calculation are saved;hardware programming,firmware control,power/thermal measurement,fuse/contact interruption tests and service-time validation have not run. Source PDFs/images remain ignored local references;none are copied into the public repository. Do not start PCB placement or call this safe to power,validated,competition legal or full-power ready.

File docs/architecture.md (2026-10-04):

# Prototype Rev A — 2026-10-04 delegated decisions

ユーザーの委任に基づき、セル監視RAM設定・exact passive選定・外部ベンチ遮断アセンブリ・保護/熱/放電検証基準を[現行選定書](rev_a_design_freeze.md)へ確定した。選定はPrototype Assumption、実測検証は未実施。平均cap電流の初期上限9.5 A、OC約12 A、目標遮断0.5 µs、各link bulk6×470 µF、precharge timeout3 s。12 A/120 Wは後続の検証目標として保持。PCB placement/通電は開始しない。以下の2026-10-03以前の未選定表示は経緯記録であり、この選定書が優先する。

# Prototype Rev A — current status

2026-10-03 JST。**Current: Prototype Rev A schematic only.** Task2 architectureはユーザー採用承認済み。実機条件未確認は[Prototype envelope](../docs/prototype_rev_a_envelope.md)に明示した **ASSUMPTION — MUST VERIFY ON PROTOTYPE** として隔離し、詳細electrical schematicを作成した。部品/保護閾値はprototype候補で性能保証ではない。[現行review](../docs/rev_a_schematic_review.md)と[pinout](../docs/pinout.md)が現在の設計記録。PCB placement/routing、firmware、通電、120W使用許可、競技適合、Task4開始は未承認。以下の旧status/approval pending/skeleton-only記述はhistorical recordであり現在statusではない。

## Rev A concrete hierarchy

POWER_INPUT / AUXILIARY_POWER / CONTROLLER / GATE_DRIVER / POWER_STAGE / CURRENT_SENSING / VOLTAGE_SENSING / TEMPERATURE_SENSING / PRECHARGE / SUPERCAP_BANK / SAFE_DISCHARGE / CAN / SAFETY, with SENSING overview. INDUCTOR is the actual22µH element in POWER_STAGE. Global labels and wires connect actual package pins. Independent latch/AND kill is implemented; control software and autonomous monitor provisioning remain future work. Power modes below remain conceptual requirements. OFF never implies stored-energy-safe.

## Historical records (preserved)

# Task 2 system architecture

[選択理由とbudget](task2_decisions.md)。以下はAssumption、保護要求はConfirmed、回路未実装。

```mermaid
flowchart LR
 R[Referee Chassis bus] <--> I[Input protection and independent disconnect]
 I <--> P[Resistor precharge and bypass / local DC link]
 P <--> D[Four-switch bidirectional converter concept]
 D <--> O[Official supercap management module]
 O <--> K[Bank-side isolation / single bank power port]
 K <--> C[9S bank proposal / cell monitoring]
 I --> A[Control auxiliary supply]
 A --> M[Controller G474RE proposal]
 S[Bus / bank / inductor current and voltage / temperature] --> M
 M -->|PWM and enable request| D
 M <--> CAN[Robot CAN transceiver]
 O --> RCAN[Referee CAN1]
 H[Independent OC / OV / watchdog / supervisor latch] -->|kill / disconnect| D
 H --> I
 H --> K
 H -->|HRTIM fault / break| M
 C --> B[Bleed / controlled and service discharge / voltage indication]
```

referee断電時assistも止める。disconnect配置と公式single port/検査path適合はTBD。graphは電気的導通の実装ではない。

## Operating modes

B=bus main isolation、C=bank transfer isolation。O=open、X=closed、P=limited precharge path。bank bleed/monitorはtransfer isolationと別に残る。

| Mode | Bus / capacitor connection | Converter | Current direction | MCU | Safety state |
|---|---|---|---|---|---|
| OFF | B O / C O | inhibited | transfer none | off or inhibited | 残留energyあり得る、Safe表示禁止 |
| Safe / discharged | B O / C O | inhibited | bleed only | off/monitor | 全domain voltage/energy・reboundを確認済み |
| Startup | B O / C O | inhibited | aux only | reset→self-test | external kill保持 |
| Precharge | B P / C O→P | inhibited; bank soft-chargeは次mode | bus→DC link limited | ΔV/I/time監視 | bypass条件確認、timeout latch |
| Charge | B X / C X | buck/boost current control | Bus→Cap | current inner / power outer | cell OV/current/thermal監視 |
| Standby | B X / C X or O | zero current/inhibited | none allowed | monitor | body diode防止、arm条件保持 |
| Assist / discharge | B X / C X | buck/boost current control | Cap→Bus | inner current / bus & power supervisor | referee cut/UV/thermal優先 |
| Regenerative / reverse-power | B/C opening request | inhibited | unsolicited current prohibited | detect/log | 初号機regen吸収未許可、isolation要求 |
| Fault | B/C O requested, feedback確認 | hardware inhibited | transfer prohibited; safe bleed conditional | log/latched | open失敗はCritical |
| Controlled shutdown | zero-current→B O / C O | ramp→inhibited | approved thermal dump only | discharge/voltage確認 | Safe移行は測定後 |
| Emergency shutdown | B/C emergency open requested | independent kill | fault energy remains until interrupted | optional logging | latch/lockout、OFFでもSafeではない |

allowed: OFF→Startup→Precharge→Standby→Charge/Assist。Charge/Assist→Standbyはzero確認。全active→Fault/Emergencyは無条件優先。Controlled shutdown→Safeは全domain検証後。Safe→Startupは再arm/self-testから。
prohibited: OFF/Startup→Assist直行、Precharge未完了→bypass閉、Charge↔Assist直接反転、Fault→自動復帰、referee cutoff中assist、regen→自動Charge、測定なしOFF→Safe。正常でもzero currentの確認不能ならFault。

Control: signed inductor-current inner loop、referee input power/energy/bus/thermal outer loop、external fault latchが全制御をoverride。ADCはPWM同期しquiet windowを確保。firmware未実装。

---

## Task 1 record (historical; Task 2 above takes precedence)

# System architecture

Concept / Assumption。最終topology、定格、pin、保護回路はTBD。

```mermaid
flowchart LR
 B[Robot Power Bus] <--> P[Input Protection and isolation candidate]
 P <--> D[Bidirectional Power Converter / topology TBD]
 D <--> O[Official management interface / placement TBD by rules]
 O <--> C[Supercapacitor Bank]
 C --> X[Independent service discharge / bleed candidate]
 P --> A[Auxiliary supply / source and hold-up TBD]
 A --> M[Controller MCU]
 B --> V[Bus Voltage Sense]
 C --> W[Capacitor and cell Voltage Sense]
 D --> I[Current Sense]
 D --> T[Temperature Sense]
 C --> T
 V --> M
 W --> M
 I --> M
 T --> M
 M --> G[Gate Driver Control]
 G --> D
 F[Independent safety / latched fault] --> G
 I --> F
 W --> F
 F --> M
 M <--> N[CAN Communication / robot controller]
```

概念power pathはBus ⇄ Input Protection ⇄ Bidirectional Converter ⇄ Bank。
図中の公式管理moduleは採用位置のplaceholderで、最新版接続図確認まで製造用接続図にしない。
Bank側・bus側で故障energy供給源が異なる。input protectionだけでbank短絡を止められるとは限らない。

## Mode definitions

全mode共通: 硬故障はFへ。PWM OFFはbody diode導通やMOSFET shortを遮断しない。
隔離とbleedは機能要件であり未実装。表中activeは将来の意図。

| Mode | Power flow | Active components | Allowed transition and guard | Prohibited transition |
|---|---|---|---|---|
| A Startup / safe | 意図的energy transferなし。残留energyは未知として扱う | aux、reset supervisor、sense、inhibit。PWM OFF | B: self-test合格・polarity正常・limits承認。G: shutdown要求。F: fault | C/Eへ直接、reset後の自動再arm |
| B Precharge | 選んだport間のΔVをcurrent-limited pathで解消 | precharge candidate、sense、timer。main path/PWMはまだ許可しない | D: ΔVと時間/current基準合格、main接続確認。F: timeout/異常。G: 中止 | bypass直結、未完了でC/E |
| C Charging | bus → bank、bus power budgetとcell限界内 | converter、sense、balancing候補、independent trip、CAN | D: current ramp→zero確認。F/G | Eへ直接、cell OV時継続 |
| D Standby | 意図的transfer zero。balancing/bleed leakageは別計測 | sense、CAN、fault path。PWMは原則OFF | C/E: fresh許可・self-test・限界内。B: 再接続要。G/F | stale CAN commandによる再開 |
| E Discharging / assist | bank → robot、regen/source限界を守る | converter、sense、fault path、CAN | D: current ramp→zero確認。F/G | Cへ直接、UV/thermal/CAN loss時継続 |
| F Fault | controlled transfer停止。短絡時は隔離/energy制限、放電はfault内容で判断 | independent latch、isolation候補、ログ。bleedは安全確認時のみ | G: fault原因評価後の放電手順。A: 原因除去・明示reset・再self-test | C/Eへの直接復帰、通信復帰だけの再arm、無条件bleed ON |
| G Shutdown | robotとのtransfer停止、隔離後bank→放電path(安全なら) | discharge/service path、voltage確認。aux消失時もservice可能な手段 | H: approved voltage/energy/timeと再上昇確認を満たす。F: 放電不能。A: 明示再起動 | Hへの時間だけの遷移、main path自動再接続 |
| H Stored-energy-safe | 意図的供給なし、全cell/隔離部分含めsafeを確認 | measured indication、lockout。bleed継続は方式次第 | A: service終了・点検・明示起動 | C/E直行、表示LED消灯だけでsafe判定 |

CAN loss → F/inhibitを保守的方針とする。robotのbase bus供給を失わせるかは接続構成で別途評価し、assist停止とrobot主電源遮断を同一視しない。
充放電方向の変更はDを経由しzero current確認する。閾値・debounce・latencyはTBD。
input loss時はcapacitorからauxへ逆給電する可能性を検討し、意図せぬ再起動を拒否する。

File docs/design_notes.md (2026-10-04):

# Prototype Rev A — 2026-10-04 delegated decisions

ユーザーの委任に基づき、セル監視RAM設定・exact passive選定・外部ベンチ遮断アセンブリ・保護/熱/放電検証基準を[現行選定書](rev_a_design_freeze.md)へ確定した。選定はPrototype Assumption、実測検証は未実施。平均cap電流の初期上限9.5 A、OC約12 A、目標遮断0.5 µs、各link bulk6×470 µF、precharge timeout3 s。12 A/120 Wは後続の検証目標として保持。PCB placement/通電は開始しない。以下の2026-10-03以前の未選定表示は経緯記録であり、この選定書が優先する。

# Prototype Rev A — current status

2026-10-03 JST。**Current: Prototype Rev A schematic only.** Task2 architectureはユーザー採用承認済み。実機条件未確認は[Prototype envelope](../docs/prototype_rev_a_envelope.md)に明示した **ASSUMPTION — MUST VERIFY ON PROTOTYPE** として隔離し、詳細electrical schematicを作成した。部品/保護閾値はprototype候補で性能保証ではない。[現行review](../docs/rev_a_schematic_review.md)と[pinout](../docs/pinout.md)が現在の設計記録。PCB placement/routing、firmware、通電、120W使用許可、競技適合、Task4開始は未承認。以下の旧status/approval pending/skeleton-only記述はhistorical recordであり現在statusではない。

## Rev A current tuning and calculations

See selected-candidate model simulation/rev_a_budget.py/report. Gate series4.7Ω, separate turn-off DNI2.2Ω/diode, DNI10Ω/1nF snubbers, OC divider options, cell configuration, precharge100Ω, dump100Ω, NTC thresholds and CAN termination are tunable. Safety functions themselves are fitted/mandatory. 22µH at100kHz fails the3App modeled worst corner;200kHz primary reduces it to2.23App. Core/Qrr/Coss/aux/connector loss and equal-rail modulation remain unmodeled. No copper layout has begun.

## Historical records (preserved)

# Task 4 design notes — placement deferred

[独立レビュー](task4_review.md)、[PCB strategy proposal](task4_pcb_strategy.md)、[baseline results](task4_baseline.md)を参照。4-layer第一案、hot/gate loop、continuous reference、Kelvin、high-current rule register、thermal/connector/debug方針は提案。実netclass/footprint/outline/placementは未実装。Task 4 §1の重大TBD gateは未通過。

---

# Task 2 design notes

選定・計算・balancing比較・L/ripple・semiconductor/driver要求・sensor/marginは[task2_decisions.md](task2_decisions.md)。再計算は[power_budget.py](../simulation/power_budget.py)。

Ceq=(Σ1/Ci)^−1、同一cellならCcell/N。ESRbank=ΣESRi。E=1/2 Ceq V²、Eusable=1/2 Ceq(Vmax²−Vmin²)。ΔQi一定でもVi=Qi/Ciはばらつき、sum電圧で個別OVを保証しない。usable energyはセルUV/OV・aging/温度・ESR terminal drop・power clampでさらに減る。

Precharge R/t/熱はClinkとΔVから、dumpは全stored energyと放電時間から算出。connectorは実RMS/peak・接触劣化・周囲温度・DC遮断と公式15 A制限を確認。current sensor rangeはerror/ripple/trip marginを残すがADC resolutionと両立。thermal marginは最悪ambient/hotspot/lagに基づく、根拠のない一律倍率なし。

PCB方針: short high-current paths、最小switching/gate loops、power/signal returnを経路として管理、shunt Kelvin、thermal copper、FET/L冷却、connector contact/via/bank cell path温度検証。routing/銅厚/部品定格は未設計。

---

## Task 1 record (historical; Task 2 above takes precedence)

# Design notes — no final component values

以下は一般原理に基づく候補分析。採用・定格・loop設計はTBD。source固有の構成は [comparison](reference_comparison.md) と [references](../references.md)。

## Capacitor bank

検討入力: cell makerのsingle-cell許容電圧とderating、N series / M parallel、C tolerance、leakage、ESR vs温度/aging/frequency、continuous/pulse current、life、thermal、mounting、vent clearance、balancing、service discharge。

- 単一理想等価cap: `E = (1/2) C V²`。
- series: `1/Ceq = Σ(1/Ci)`。同一cell N個では `Ceq = Ccell/N`。
- 同一series stringをM並列なら `Cbank = M Ccell/N`。並列stringにもcurrent-sharingと個別fault pathがある。
- series ESRは和、同一string並列なら概ねstring ESR/M。接続抵抗・温度差・frequency依存を加える。
- 全energyは `Σ(1/2 Ci Vi²)`。balanced状態でのみ等価bank式との整合を単純化できる。
- usable ideal energy: `(1/2) Ceq (Vhi² - Vlo²)`。実際はconverter損失・ESR sag・UV marginを引く。
- loss: `P_ESR = Irms² ESR`、step sag: `ΔV ≈ I ESR`、ideal charge: `dV/dt = I/C`。
- seriesではchargeが同じでも `ΔVi = ΔQ/Ci` が異なる。leakage差はDC imbalanceを作る。bank total Vだけではcell OVを検出できない。
- nominal energy規則が耐圧基準なら動作電圧を下げただけでnominal capacityが減るとは扱わない。
- cell数・bank最大電圧・safe voltage/energyはhuman gateでTBD。mechanical retention、絶縁、cell tap short防護を同時に決める。

## Cell balancing

方式は排他的でない。IC-basedにはpassive shunt制御もactive transferも含まれる。

| Method | Complexity | Power loss | Speed | Reliability | Fault behavior / suitability |
|---|---|---|---|---|---|
| passive resistor | 低 | 常時Vi²/R、長期自己放電 | 小電流なら遅い | 単純だが熱・抵抗tol管理 | openでbalance喪失、shortでcell discharge/発熱。leakageばらつき対策候補、fast charge OV保護の代替不可 |
| active transfer | 高、switch/magnetics追加 | standbyと変換損失、抵抗より省energyの可能性 | 定格transfer current次第 | 制御・short pathsが増える | 誤制御で弱いcellへenergy集中、switch短絡。頻繁な高energy運用なら候補 |
| IC-based monitor/balance | 中〜高 | passive/active方式による | IC current/thermal制限次第 | 診断を集約、common-cause注意 | supply loss、tap断線、IC故障を検出。正確なcell監視と独立trip候補 |

balancingはOV protectionと別機能。温度とleakage最大差に対して充電速度に追従するか検証する。

## Topology versus voltage envelope

| Candidate | Voltage relationship / function | Advantages | Disadvantages | Control complexity | Expected component count |
|---|---|---|---|---|---|
| charge buck + separate assist boost | Vcap < Vbus全域を保証した場合の充電降圧・放電昇圧 | 方向ごと理解容易、機能分離 | 2 stageと交差path、voltage crossingに不適 | 中、2 controller/mode arbitration | 2 inductive stages、各switch/rectifier/保護 |
| two-switch bidirectional half-bridge | fixed high port=bus、low port=bank、Vcap < Vbusに十分margin | 少部品、charge buck / assist boostを同じLで | equality近傍・Vcap>Vbusに制約、diode path | 中、signed current/zero-cross/deadtime | half bridge 2 FET + L + driver、補助/遮断部品別 |
| four-switch bidirectional synchronous buck-boost | bankがbus上下に跨る範囲 | 両方向step-up/down、energy利用範囲広い | switching loss、driver数、mode移行の複雑さ | 高、2 bridge協調、current direction、fault timing | 4 FET + L + 2 half-bridge drivers、補助/遮断別 |

数は概念stageで、parallel FET/phase、filter、sense、fuse、prechargeは含まない。
boost-onlyはcharge方向も含めた全機能を満たさず、buck-onlyも低bank電圧からbus assist不可。
非同期diode converterは一般に一方向。synchronous化は効率と双方向制御の可能性を与えるが、逆流防止を自動保証しない。
half bridgeはswitch構成であり、それ自体を独立したbuck/boostとは決めない。port関係・L接続・制御で機能が変わる。
single phase vs多相は別軸。最初にvoltage envelopeとfault isolationを決めてから比較する。

## Block design intent extraction

| Block / Function | Typical implementation | Advantages | Disadvantages | Common failure mode | RoboMaster suitability |
|---|---|---|---|---|---|
| buck / voltage reduction | switch + diode/L、またはsync half bridge | chargeに単純 | step-up不可 | switch shortでbankへbus直結 | Vcap下側だけの充電候補 |
| boost / voltage increase | L + low-side switch + rectifier | low capからassist | deep dischargeでcurrent増大 | switch short / output diode backfeed | bank下側の放電候補 |
| buck-boost / step up/down | 非反転four switchなど | voltage crossingに対応 | switchと制御増加 | mode切替shoot-through | envelope未知なら比較対象 |
| bidirectional buck-boost / reversible transfer | signed current feedback + sync bridges | 共通stageでenergy buffer | fault時2 sourceから供給 | current polarity誤認、gate fault | 有力、採用TBD |
| half bridge / PWM switching leg | complementary FET + deadtime driver | 同期switch基礎 | floating high-side供給 | 同時ON / bootstrap不足 | fault inputとdeadtime検証必須 |
| synchronous converter / loss reduction | diodeをcontrolled FETへ | conduction損失低減 | 軽負荷逆流・shoot-through | deadtime違反、stuck gate | current directionとhardware tripが条件 |
| input protection / polarity and fault boundary | fuse + isolation candidate + transient clamp | robot/sourceを保護 | DC interruption/熱/arc設計必要 | FET短絡、fuse未溶断 | bank側pathも別検討 |
| precharge / inrush control | resistor+bypass / active limiter / converter soft start | connector arcを抑制 | resistor熱とsequence増加 | bypass stuck、timeout無視 | 起動経路全部を検討 |
| sensing / observability | ADC conditioning + independent comparator candidate | 制御/diagnostics | noise/校正/common cause | open/stuck/reference mismatch | signed currentとcell監視重要 |
| safety / energy containment | independent inhibit + latch + isolation | MCU crashへ耐性 | common supply故障は残る | shared sensor/reference故障 | 必須要求、未実装 |
| discharge / service | passive bleed / controlled sink / removable service tool | OFF後のenergy低減 | 熱・time・bus loss依存 | resistor open、indicator消灯誤認 | 独立測定とlockoutが条件 |

## MCU candidates

| Candidate | ADC/PWM/fault | CAN / interfaces | Tradeoff |
|---|---|---|---|
| STM32G4、G474-class | HRTIM、PWM-triggered ADC、comparators/fault input候補 | FDCAN、UART、SPI/I2C | peripheral余裕、pin mux / package / errata / cost確認必要。G4全型番にHRTIMがあるとは仮定しない |
| STM32F334-class | HRTIM、ADC、comparator/op-amp候補 | Classic CAN、UART、SPI/I2C | 比較的少resource。memoryとloop timing余裕を評価 |

ST AN5094と各datasheet/errataを入口にする。temperature/current measurementはADC front-endとsystem設計で決まり、MCU内蔵temperatureはpower component temperatureの代替でない。
HRTIM fault tripもMCU/clock/supplyに依存するためexternal inhibitの代替とは断定しない。exact part/packageを選定しpin番号をdatasheetで確認する。

## Current sensing

Hallはmagnetic sensingの一方式。ここでmagnetic候補はAMR/TMR等を指し、製品の構造と絶縁を個別確認する。

| Method | Bidirectional / bandwidth | Isolation / accuracy | Loss | Cost / area | Fault behavior |
|---|---|---|---|---|
| shunt + amplifier | offset referenceでsigned測定、PWM同期可。amp/filter bandwidth要設計 | 一般に非絶縁、offset/gain/temp/CMR影響 | I²R、hotspot | 低〜中、Kelvin配線とthermal面積 | shunt open、amp saturation、reference故障。fast comparator branch候補 |
| Hall | signed対応製品を選択、帯域は個別datasheet | 絶縁型もある、offset/drift/外部磁場影響 | conductor抵抗による | 中〜高、一般に大きめ | supply loss、offset、magnetic saturationを診断 |
| AMR/TMR等magnetic | signed対応/帯域は製品次第 | 絶縁はsensor方式だけでは保証されない | conductor loss、shunt不要の可能性 | 中〜高、geometry/磁気配置に依存 | 外部磁場、saturation、供給故障 |

制御senseとshort-circuit protectionの必要帯域は別。bus/bank/inductorどのpointを監視するかでpeak/average関係が変わる。

## Voltage and temperature sensing

bus Vはsource状態・OV・power計算、bank Vはenergy・converter envelope、cell Vはimbalance・OV/UVに必要。
series bankでbank totalのみの監視は不十分。per-cell monitorは要求として検討し方式/診断/independent tripをgateで決める。
ADCはdivider tolerance、RC settling、input range、transient clamp、series impedance、injection current、MCU unpowered時backfeed、tap断線/短絡、reference診断を設計する。回路値TBD。
firmware referenceと実装referenceを一致させ、校正versionを検証する。

MOSFETはjunction推定とpackage温度差、inductorはwinding/core hotspot、bankはESRと寿命の温度を評価する。
初期候補はpower-stage hotspot + bank。inductorとMOSFETを1 sensorで兼用する場合は両者の温度差/応答を実測し、保守的marginで保護できることが条件。
sensor open/shortは低温と誤認しない。fan failure/zero-airflowも評価。全箇所sensorを無条件必須としないが、未監視hotspotの根拠を記録する。

## Precharge / emergency discharge

large bankだけでなくbus decoupling、diode bypass、connector挿入時の充放電両方向ΔVを調べる。
候補: resistor + bypass、active current limiter、converter-controlled soft start。soft startはPWM開始前のbody-diode pathを抑えられる場合だけprecharge代替になる。
`I_initial ≈ ΔV/R`、`τ = RC`、単純なRC precharge抵抗の損失energyは概ね`1/2 C(ΔV)²`。bypass weldingとtimeoutを検出する。

bleedはpassive常時(確実だが自己放電)、controlled(省energyだがaux依存)、service tool(操作・定格・lockout依存)を比較。
理想resistor discharge: `V(t)=V0 exp(-t/RC)`、`t=RC ln(V0/Vsafe)`、`P_initial=V0²/R`。cell imbalanceと誘電吸収によるvoltage reboundを加える。
safe thresholdは感電だけでなく短絡energy・工具arc・cell状態を考慮しTBD。LED消灯を証明にしない。故障中の無条件緊急放電は熱/短絡を悪化させ得る。

## PCB high-current considerations (no layout yet)

- high-current pathを短くし、bank/source両方のfault pathを可視化する。
- switching current loopとgate loopを最小化し、sense returnをswitching returnから離す。
- power GND / signal GNDの名称分離だけでなく実際のreturnを追跡し、plane cutで迂回させない。
- shunt/current senseはKelvin connection、ADC参考GNDも計測点を管理する。
- thermal copper、via、MOSFET/inductor cooling、capacitor ESR熱を評価する。
- connectorはcontinuous/pulse、ambient、接触抵抗、wire、hot unplugを含めて定格を確認する。
- capacitor pathを大電流に対応させcell tapは短絡energyを制限。mount/振動/絶縁を同時レビューする。
- 銅厚・幅・via数・fuse ratingは要求とthermal/current試験前に決めない。

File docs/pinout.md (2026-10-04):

# Prototype Rev A — 2026-10-04 delegated decisions

ユーザーの委任に基づき、セル監視RAM設定・exact passive選定・外部ベンチ遮断アセンブリ・保護/熱/放電検証基準を[現行選定書](rev_a_design_freeze.md)へ確定した。選定はPrototype Assumption、実測検証は未実施。平均cap電流の初期上限9.5 A、OC約12 A、目標遮断0.5 µs、各link bulk6×470 µF、precharge timeout3 s。12 A/120 Wは後続の検証目標として保持。PCB placement/通電は開始しない。以下の2026-10-03以前の未選定表示は経緯記録であり、この選定書が優先する。

# Prototype Rev A physical pinout

2026-10-03. STM32G474RET6/LQFP64. Pin numbers and AF functions checked against ST DS12288 Table12/13 and manufacturer package data. This is a schematic allocation, not firmware or PCB completion. VDD3.3V; analog0..3.3V only. HSI clock provisional. **PB8 is also BOOT0: nSWBOOT0/nBOOT0 option-bit policy must force flash boot before use; CAN idle HIGH cannot serve as a LOW boot strap.** PG10 option must enable NRST. Option programming is not implemented.

| Physical pin | Pad / schematic pin name | Signal | Function / AF | Default / note |
|---|---|---|---|---|
| 1 | VBAT | V3V3 | supply | see interface/power sequencing |
| 2 | PC13 | PRE_CAP_FB | GPIO | input / no drive |
| 3 | PC14 | NC spare | unused | see interface/power sequencing |
| 4 | PC15 | NC spare | unused | see interface/power sequencing |
| 5 | PF0 | NC spare | unused | see interface/power sequencing |
| 6 | PF1 | NC spare | unused | see interface/power sequencing |
| 7 | PG10 | NRST | reset | see interface/power sequencing |
| 8 | PC0 | TEMP_FET_ADC | ADC12_IN6 | input / no drive |
| 9 | PC1 | TEMP_L_ADC | ADC12_IN7 | input / no drive |
| 10 | PC2 | TEMP_BANK_ADC | ADC12_IN8 | input / no drive |
| 11 | PC3 | BUS_RAW_ADC | ADC12_IN9 | input / no drive |
| 12 | PA0 | BUS_V_ADC | ADC12_IN1 | input / no drive |
| 13 | PA1 | CAP_V_ADC | ADC12_IN2 | input / no drive |
| 14 | PA2 | UART_TX | AF7 USART2_TX | see interface/power sequencing |
| 15 | VSS | GND | supply | see interface/power sequencing |
| 16 | VDD | V3V3 | supply | see interface/power sequencing |
| 17 | PA3 | UART_RX | AF7 USART2_RX | see interface/power sequencing |
| 18 | PA4 | BUS_I_ADC | ADC2_IN17 | input / no drive |
| 19 | PA5 | CAP_I_ADC | ADC2_IN13 | input / no drive |
| 20 | PA6 | IL_I_ADC | ADC2_IN3 | input / no drive |
| 21 | PA7 | NC spare | unused | see interface/power sequencing |
| 22 | PC4 | CAP_RAW_ADC | ADC2_IN5 | input / no drive |
| 23 | PC5 | REFEREE_PERMIT | GPIO | see interface/power sequencing |
| 24 | PB0 | ARM_PULSE | GPIO | LOW / disabled |
| 25 | PB1 | WD_HEARTBEAT | GPIO | LOW / disabled |
| 26 | PB2 | MCU_GATE_REQUEST | GPIO | LOW / disabled |
| 27 | VSSA | GND | supply | see interface/power sequencing |
| 28 | VREF+ | VREF_ADC | supply | see interface/power sequencing |
| 29 | VDDA | VDDA | supply | see interface/power sequencing |
| 30 | PB10 | PRE_BUS_REQUEST | GPIO | LOW / disabled |
| 31 | VSS | GND | supply | see interface/power sequencing |
| 32 | VDD | V3V3 | supply | see interface/power sequencing |
| 33 | PB11 | BYP_BUS_REQUEST | GPIO | LOW / disabled |
| 34 | PB12 | MON_CS_HOST | GPIO | see interface/power sequencing |
| 35 | PB13 | MON_SCLK_HOST | AF5 SPI2_SCK | see interface/power sequencing |
| 36 | PB14 | MON_MISO_HOST | AF5 SPI2_MISO | see interface/power sequencing |
| 37 | PB15 | MON_MOSI_HOST | AF5 SPI2_MOSI | see interface/power sequencing |
| 38 | PC6 | BUS_ISO_REQUEST | GPIO | LOW / disabled |
| 39 | PC7 | CAP_ISO_REQUEST | GPIO | LOW / disabled |
| 40 | PC8 | PRE_CAP_REQUEST | GPIO | LOW / disabled |
| 41 | PC9 | BYP_CAP_REQUEST | GPIO | LOW / disabled |
| 42 | PA8 | PWM_AH | AF13 HRTIM_CHA1 | LOW / disabled |
| 43 | PA9 | PWM_AL | AF13 HRTIM_CHA2 | LOW / disabled |
| 44 | PA10 | PWM_BH | AF13 HRTIM_CHB1 | LOW / disabled |
| 45 | PA11 | PWM_BL | AF13 HRTIM_CHB2 | LOW / disabled |
| 46 | PA12 | HW_FAULT_N | AF13 HRTIM_FLT1 active LOW | see interface/power sequencing |
| 47 | VSS | GND | supply | see interface/power sequencing |
| 48 | VDD | V3V3 | supply | see interface/power sequencing |
| 49 | PA13 | SWDIO | AF0 SWDIO | see interface/power sequencing |
| 50 | PA14 | SWCLK | AF0 SWCLK | see interface/power sequencing |
| 51 | PA15 | PRE_BUS_FB | GPIO | input / no drive |
| 52 | PC10 | DUMP_REQUEST | GPIO | LOW / disabled |
| 53 | PC11 | MON_ALERT_HOST | GPIO | see interface/power sequencing |
| 54 | PC12 | CAN_STANDBY | GPIO | see interface/power sequencing |
| 55 | PD2 | MON_CONFIG_VALID | GPIO | LOW / disabled |
| 56 | PB3 | SWO | AF0 SWO | see interface/power sequencing |
| 57 | PB4 | BUS_ISO_FB | GPIO | input / no drive |
| 58 | PB5 | CAP_ISO_FB | GPIO | input / no drive |
| 59 | PB6 | BYP_BUS_FB | GPIO | input / no drive |
| 60 | PB7 | BYP_CAP_FB | GPIO | input / no drive |
| 61 | PB8 | CAN_RX | AF9 FDCAN1_RX | see interface/power sequencing |
| 62 | PB9 | CAN_TX | AF9 FDCAN1_TX | see interface/power sequencing |
| 63 | VSS | GND | supply | see interface/power sequencing |
| 64 | VDD | V3V3 | supply | see interface/power sequencing |

ADC uses HRTIM-triggered conversions away from edges;12-bit nominal resolution is not effective accuracy. Multiple ADC/DMA scheduling and INA240 settling at200kHz must be tested. External comparator path drives FLT1; internal MCU comparators are unassigned expansion, not primary protection. Five unused GPIO pads are PC14/PC15/PF0/PF1/PA7. Debug power pin is a voltage reference only.

## Major component pin → datasheet terminal → footprint pad

Original box symbols are maintained in tools/rev_a_parts.py; numbers are physical except the explicitly grouped MOSFET aliases below. Installed candidate footprints were checked for pad-set equivalence, not certified land geometry.

| Component | Symbol pin:function / datasheet equivalent | Candidate footprint |
|---|---|---|
| Q_NPN | 1:B, 2:E, 3:C | Package_TO_SOT_SMD:SOT-23 |
| Q_PNP | 1:B, 2:E, 3:C | Package_TO_SOT_SMD:SOT-23 |
| FUSE | 1:A, 2:B | external / TBD |
| CSD18540Q5B | 1:S_DS1_2_3, 2:G_DS4, 3:D_DS5_6_7_8 | Package_SON:VSONP-8-1EP_5x6_P1.27mm |
| UCC27282DRCR | 1:VDD, 2:NC, 3:HB, 4:HO, 5:HS, 6:EN, 7:HI, 8:LI, 9:VSS, 10:LO, 11:EP | Package_SON:VSON-10-1EP_3x3mm_P0.5mm_EP1.65x2.4mm |
| INA240A1D | 1:INM, 2:GND, 3:REF2, 4:NC, 5:OUT, 6:VS, 7:REF1, 8:INP | Package_SO:SOIC-8_3.9x4.9mm_P1.27mm |
| INA240A2D | 1:INM, 2:GND, 3:REF2, 4:NC, 5:OUT, 6:VS, 7:REF1, 8:INP | Package_SO:SOIC-8_3.9x4.9mm_P1.27mm |
| WSK25123L000FEA | 1:I_P, 2:K_P, 3:K_M, 4:I_M | Resistor_SMD:R_Shunt_Vishay_WSK2512_6332Metric_T2.21mm |
| INA293A1DBVR | 1:OUT, 2:GND, 3:INP, 4:INM, 5:VS | Package_TO_SOT_SMD:SOT-23-5 |
| INA301A1DGKR | 1:VS, 2:OUT, 3:LIMIT, 4:GND, 5:RESET, 6:ALERT_N, 7:INM, 8:INP | Package_SO:VSSOP-8_3x3mm_P0.65mm |
| TLV3202DGKR | 1:OUT1, 2:INM1, 3:INP1, 4:GND, 5:INP2, 6:INM2, 7:OUT2, 8:VCC | Package_SO:VSSOP-8_3x3mm_P0.65mm |
| SN74LVC1G74DCUR | 1:CLK, 2:D, 3:QN, 4:GND, 5:Q, 6:CLR_N, 7:PRE_N, 8:VCC | Package_SO:VSSOP-8_2.3x2mm_P0.5mm |
| SN74LVC2G08DCUR | 1:A1, 2:B1, 3:Y2, 4:GND, 5:A2, 6:B2, 7:Y1, 8:VCC | Package_SO:VSSOP-8_2.3x2mm_P0.5mm |
| TPS3431SDRBR | 1:VDD, 2:CWD, 3:EN, 4:GND, 5:SET1, 6:WDI, 7:WDO_N, 8:ENOUT, 9:EP | Package_SON:VSON-8-1EP_3x3mm_P0.65mm_EP1.65x2.4mm |
| TPS3839K33DBZR | 1:GND, 2:RESET_N, 3:VDD | Package_TO_SOT_SMD:SOT-23 |
| LM5164DDAR | 1:GND, 2:VIN, 3:EN, 4:RON, 5:FB, 6:PGOOD, 7:BST, 8:SW, 9:EP | Package_SO:TI_SO-PowerPAD-8 |
| TMUX1511PWR | 1:SEL1, 2:S1, 3:D1, 4:SEL2, 5:S2, 6:D2, 7:GND, 8:D3, 9:S3, 10:SEL3, 11:D4, 12:S4, 13:SEL4, 14:VDD | Package_SO:TSSOP-14_4.4x5mm_P0.65mm |
| TLV431AIDBZR | 1:REF, 2:K, 3:A | Package_TO_SOT_SMD:SOT-23 |
| SN65HVD230DR | 1:D, 2:GND, 3:VCC, 4:R, 5:VREF, 6:CANL, 7:CANH, 8:RS | Package_SO:SOIC-8_3.9x4.9mm_P1.27mm |
| SN74LV1T34DBVR | 1:NC, 2:A, 3:GND, 4:Y, 5:VCC | Package_TO_SOT_SMD:SOT-23-5 |
| BQ7694204PFBR | 1:NC, 2:VC9, 3:NC, 4:VC8, 5:NC, 6:VC7, 7:NC, 8:VC6, 9:NC, 10:VC5, 11:NC, 12:VC4, 13:VC3, 14:VC2, 15:VC1, 16:VC0, 17:VSS, 18:SRP, 19:NC, 20:SRN, 21:TS1, 22:TS2, 23:TS3, 24:REG18, 25:ALERT, 26:SCLK, 27:MISO, 28:MOSI, 29:CS_N, 30:DFETOFF, 31:DCHG, 32:DDSG, 33:RST_SHUT, 34:REG2, 35:REG1, 36:REGIN, 37:BREG, 38:FUSE, 39:PDSG, 40:PCHG, 41:LD, 42:PACK, 43:DSG, 44:NC, 45:CHG, 46:CP1, 47:BAT, 48:VC10 | Package_QFP:TQFP-48_7x7mm_P0.5mm |
| CONTACT | 1:COM, 2:NO, 3:COIL_P, 4:COIL_M | external / TBD |

CSD18540 functional1=S physical package leads1/2/3; functional2=G lead4; functional3=D leads5/6/7/8 and drain metal. KiCad VSONP footprint groups these as1/2/3; **not literal manufacturer 8-pin numbering**. WSK2512 grouped1=I+,2=Kelvin+,3=Kelvin−,4=I−; inspect terminal view and PCB current direction before routing. UCC27282 EP11 and LM5164 EP9 are ground; thermal-pad solder and vias need PCB review. BQ76942 physical48=VC10,2=VC9; VC9/VC8 short is deliberate unused-channel handling, not a missing ninth cell.

## External selected-module physical pin supplement

| Module | Manufacturer terminal mapping | PCB land |
|---|---|---|
| AQZ202G |1 LED−,2 LED+,3/4 AC/DC load|External,no PCB footprint|
| DDR-60L-12 |1/2 −Vo,3/4 +Vo,5 +Vin,6 −Vin|External DIN module|

PRE_BUS_FB/ PRE_CAP_FB are reserved inputs pulled LOW;SSR conduction is inferred from raw/link voltage progression,not an invented auxiliary contact. Existing64-pin MCU allocation is unchanged.

AEV14012 main-contact FB headers are also reserved diagnostic inputs,default LOW;the selected contactor has no intrinsic auxiliary feedback. Firmware must not interpret an unconnected pin as closed-contact proof. Raw/link ADC progression,current response and independently inspected isolation establish behavior;welded-contact fault tests remain required.

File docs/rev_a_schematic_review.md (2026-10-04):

# Prototype Rev A — 2026-10-04 delegated decisions

ユーザーの委任に基づき、セル監視RAM設定・exact passive選定・外部ベンチ遮断アセンブリ・保護/熱/放電検証基準を[現行選定書](rev_a_design_freeze.md)へ確定した。選定はPrototype Assumption、実測検証は未実施。平均cap電流の初期上限9.5 A、OC約12 A、目標遮断0.5 µs、各link bulk6×470 µF、precharge timeout3 s。12 A/120 Wは後続の検証目標として保持。PCB placement/通電は開始しない。以下の2026-10-03以前の未選定表示は経緯記録であり、この選定書が優先する。

# Prototype Rev A schematic review

2026-10-03 JST. **Prototype Rev A schematic only.** Architecture is adopted; prototype numeric settings are **ASSUMPTION — MUST VERIFY ON PROTOTYPE**, thresholds **PROVISIONAL — MUST VALIDATE**. Unknown physical conditions no longer prohibit drawing circuits. Energizing, 120 W operation, continuous thermal limits, final OC, service-safe time and interruption capability remain unapproved. No PCB placement/routing or firmware was performed.

## Selected candidates and reasons

| Block | Primary / alternative | Decision and limitations |
|---|---|---|
| MOSFET | CSD18540Q5B / CSD18563Q5A | 60 V both. Primary max25C RDS2.2mΩ vs6.8mΩ at10V, favors conduction at12A. Qg max53 vs20nC; Qrr typ145 vs63nC at different tests. Primary pays switching/driver losses. Hot multiplier1.6 is an assumption. SOA pulse conditions and actual VDS/VGS must be checked; 60V is not proved sufficient. SON5x6 needs thermal copper; datasheet package current is not board current. |
| Driver | UCC27282DRCR / UCC27211A | Primary DRC10+EP provides EN/interlock plus UVLO. Secondary needs additional enable/interlock design. 12V rail; external HI/LI AND kill, EN pull-down, independent rail11.23..13.64V backup window, HRTIM FLT1. Internal interlock does not replace timer deadtime. |
| Inductor | XAL1510-223MED / -153MED | Select22µH at200kHz (180–200 exploration). 100kHz worst ripple4.45App exceeds3App goal;200kHz2.23App under assumed14.08µH lower L.22µH DCRmax16mΩ, Isat18.7A at30% drop, thermal10.5/14A at20/40C rise.15µH lowers DCR12.4mΩ but increases ripple. Core loss and saturation at heat remain unmodeled. |
| Signed sensing | INA240A2 bus / A1 cap and IL, 3mΩ WSK25123L000FEA | REF1=3.3, REF2=GND gives1.65V zero. Kelvin four terminals,1W at70C conditional on mounting,1% resistance,3mΩ TCR75ppm/C. Ideal bus±8A, cap/IL±20A measurement; amplifier swing and settling narrow these. |
| Fast OC | INA293A1 opposing pairs on all3 shunts + TLV3202 | Six dedicated front ends, CM−4..110V; separate from INA240/ADC. INA301 was rejected:40V absolute CM max below SMBJ28A rated45.4V clamp. Thresholds bus±8.006A, cap/IL±13.959A nominal. No guaranteed fault clearing time from bandwidth. |
| Cell monitor | BQ7694204PFBR / BQ76952 | Primary3–10cells fits9S; alternative3–16 adds unused inputs. SPI/CRC, REG1 default3.3V, programmable autonomous cell protections/open-wire and internal switched-passive balancing. **Supercap-specific configuration is NOT implemented**; Li-ion defaults cannot protect2.7V cells. Readback/provisioning is a commissioning gate. |
| Temperature | NTCLE100E3103JB0 | Three10k/β3977 probes, MOSFET area/inductor/bank. Hardware hot/short/open windows plus ADC. Approximate loaded thresholds69.5C /53.7C; calibration, sensor lag and hotspot mapping mandatory. Probe header replaces fitted NTC. |
| Aux | LM5164DDAR x2 | Bus-fed12V driver and3.3V MCU,100V IC input (not board surge guarantee). Type3 ripple injection,300kHz class,68/47µH, PG outputs and supervisor. External actuator12V is a separate unresolved assembly supply, not the1A gate-bias regulator. |
| CAN | SN65HVD230DR |3.3V Classic CAN, RS default standby, selectable120Ω. ID/rate/timing/ESD system integration TBD. Does not bypass referee power cutoff. |

## Actual electrical power path

BUS_RAW → candidate10A fuse/TVS → external NO isolation → (100Ω precharge NO path || NO bypass) → signed bus shunt → BUS_LINK.
Four CSD18540: AH D=BUS_LINK S=SW_NODE_A; AL D=SW_NODE_A S=GND; BH D=CAP_LINK S=SW_NODE_B; BL D=SW_NODE_B S=GND.
SW_NODE_A →3mΩ Kelvin IL shunt→22µH→SW_NODE_B. CAP_LINK → signed cap shunt→ cap precharge/bypass→external NO isolation→candidate15A fuse→9S bank.
Each link has470µF/63V bulk plus two2.2µF/100V1210 ceramic candidates; **bulk exact product/ripple capability is TBD**. External bank/cables/connectors/contacts are assembly boundaries, not a released onboard BOM.

Charge: bus→cap; when cap below bus, buck bus leg; if cap above bus, boost opposite leg. Assist reverses current and active-leg role. Near equal voltages requires reviewed modulation; no100% high-side hold with bootstrap. PWM details/control stability and regenerative acceptance are not implemented. Firmware must refuse unreviewed regen; diode/transient current still requires physical containment.

## Gate and protection circuits

Each driver has470nF bootstrap (effective≥200nF proposal),1µF+100nF supply decoupling,4.7Ω gate series resistors, mandatory10k G–S and15V clamp. DNI2.2Ω+diode separate turn-off and10Ω/1nF snubbers are tuning options; mandatory protection is never DNI.
Fast OC/current windows + independent bus/bank/driver voltage windows + three thermal windows + rail PG/supervisor + external200ms-typ watchdog + monitor DCHG/DDSG + commissioning valid + referee permit → combinational inhibit → SN74LVC1G74 asynchronous CLEAR → latched permit → four PWM AND gates and both driver EN. NRST clears latch. Explicit ARM rising edge required; fault disappearance does not rearm. Same fault enters PA12 HRTIM FLT1. Fast PWM input kill is primary; driver EN typ latency alone is not a short-circuit guarantee.
GPIO float/reset pulls requests LOW; unpowered driver output behavior and partial-rail logic must be measured. A watchdog heartbeat from an unconditional timer would hide crashes: future foreground firmware must qualify it with health/CAN lease. No firmware exists yet.
Shunts, references and rails are shared failure points. Local same-leg shoot-through can bypass port/IL shunts; interlock, deadtime and independently coordinated fuse/DC disconnect remain necessary. Comparator offsets, supply tolerance, recovery/blanking and current excursion are not yet a certified protection budget.

## Voltage / partial-power review

Bus/raw:2x33k top,5.1k bottom; cap/raw:2x33k,6.8k;4.7nF filtering.100k ADC-side drain loads dividers; use loaded transfer, not unloaded gain. Independent bus/bank-fed TLV4312.703V shunt clamp plus BAT54H clamps prevents intentional clamp to dead MCU VDD. Current/temp ADC channels also use TMUX1511 powered-off isolation.
TMUX1511 off protection is only≤3.6V; source/clamp diode tolerance and power sequences must stay below that. Max2µA off leakage times100k is0.2V estimate; measured injection into unpowered MCU and ADC error budget remain required. Source-powered SPI/ALERT also disconnect when either bank REG1 or MCU rail is missing; SN74LV1T34 shifts initial1.8V monitor MISO to3.3V. This is not galvanic isolation.

## Cell configuration contract

9S uses VC1..VC8 then VC10, VC9 tied VC8; enable mask0x02FF, unused channel9 disabled. Input taps each1k/1W and100nF adjacent filters. **Source-side harness resistors/short protection before the connector remain mandatory external work.** Simple raw taps are never MCU ADC connections.1k limits internal passive balancing; about1.2mA near2.45V cannot correct arbitrary charge mismatch at high charge current. Charge taper/inhibit and imbalance response required.
Before setting MON_CONFIG_VALID: configure/read back COV proposal2.55V, normal2.45V, CUV proposal1.2V (useful bank12V separately), channel mask, DCHG/DDSG ACTIVE-HIGH permits mapped to autonomous faults, SPI CRC, open-wire diagnosis and passive-balance constraints. Quantization/accuracy/hysteresis/delays require TRM-based implementation and test. OTP plan/power-cycle test TBD. DCHG/DDSG pull-down and invalid commissioning prevent arm; **GPIO-valid alone does not prove correct configuration**. SRP/SRN grounded, so BQ current protections cannot be relied on. TS dummy10k are commissioning options, not actual temperature probes; mask/control policy must explicitly use external thermal protection.
BQ minimum5V bank supply prevents normal startup from an empty bank. Dedicated energy-limited bank commissioning must precede normal use; resistor precharge is only for local links, not charging9S from0V.

## Body-diode and single-fault review

N-channel body diode is S→D. Healthy all-OFF bridge blocks steady positive rail-to-rail flow, but is not galvanic isolation and cannot extinguish arbitrary inductor/transient energy.

| Condition | Path / required response | Unresolved acceptance |
|---|---|---|
| A bus OFF, bank charged | Bus-fed aux dies, gate/contacts default OFF; bank monitor/LED/bleed remain. IL decay may feed link diode. | Leakage, contact welding, external interfaces and rebound measurement. |
| B bus ON, MCU OFF/reset | Requests pulled LOW, supervisor/latch inhibit; raw aux alive. | Floating/startup/glitch and monitor-permit power ordering. |
| C driver unpowered | EN/HI/LI low and G–S resistors discharge gates; no bootstrap refresh. | Miller turn-on, HS negative spike, discharge rate with unpowered IC. |
| D one FET short | High-side short connects that rail through L and opposite high-side body diode to other rail; low-side short grounds its node, opposite active high side can feed L short; same-leg complementary ON gives direct link short. | PWM cannot remove short. Source+bank external interruption and DC fuse coordination NOT approved. |
| E one FET open | Current commutates through remaining diode/avalanche paths; command/current disagreement should latch. | Diode heat/VDS spikes, detect latency, actual failed-open diode behavior. |
| F aux supply failure | Supervisor/PG/watchdog/window revoke PWM/contacts. Switched dump may become unavailable. | Permanent bleed + independent service tool, partial rail/backfeed, stuck driver and welded contact remain. |

## Precharge, discharge, isolation boundary

Separate local bus/cap470µF links each use100Ω AC05 candidate resistor and NO precharge contact, bypass NO contact, plus upstream NO isolation.26V ideal pulse0.159J,6.76W initial; ΔV<1V and1s timeout proposals. Contact feedback, pulse/cold/startup tests and software interlocks not implemented. Latched permission also gates all six contact commands: fault disappearance alone cannot reclose them. Startup arms the latch with MCU_GATE_REQUEST still LOW, then precharges, checks feedback and only finally requests PWM. Fault inhibits coils but welded bypass requires separate upstream isolation.
Permanent10k/1W bleed plus normally-OFF100Ω HS25 chassis dump MOSFET path, thermally qualified command. +30%C dump to1V≈37.2min,1752J; bleed≈62h. HS25 rating needs specified mounting/derating. Bus aux loss removes active dump. Bank-powered red LED does not work at1V: darkness is NOT safe. Meter every cell/link/bank, rebound and residual energy; service-safe criterion remains unapproved.
AEV14012 is only an external DC contactor candidate (120A catalog /12V coil), oversized and not a proven bidirectional interrupter for this assembly. Six contact instances require an external bus-derived ACTUATOR_12V supply whose coil budget/startup/UVLO and release are TBD; no such supply is implemented onboard. Flyback diode slows release. Fuse58V candidates have no approved I²t/breaking coordination. Manual source/bank service disconnect and branch faults need independent review. **These assembly boundaries prohibit fabrication/energizing release.**

## Validation record

See [pinout](pinout.md), [envelope](prototype_rev_a_envelope.md), [selected arithmetic](../simulation/rev_a_results.md).
KiCad10.0.6 real netlist/ERC, not empty-skeleton ERC: Errors0/Warnings0;467 exported components,329 nets,1440 pin/net matches and25 independent inhibit checks. Full evidence and limitations are in [validation record](rev_a_validation.md). No No-ERC markers. Explicit NC pins are intentional unused pins. PWR_FLAG only annotates source rails, not a safety bypass. All generated components have original symbol pin tables. Candidate footprint pad numbers audited against installed KiCad library; physical dimensions/land tolerance and every passive exact part remain independent-review gates.
Visual inspection of whole hierarchy and exact local supply/power/kill nets plus exported connectivity audit checks topology; this does not verify dynamic behavior. No PCB was edited. Firmware, monitor configuration image, external interruption assembly and thermal proof remain unfinished.

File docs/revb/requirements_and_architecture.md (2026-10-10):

# Rev B — ロボット搭載用の簡素版: 要件と構成(ドラフト)

2026-10-10。Rev A(ベンチ試作)を参考に、ロボット搭載を前提に組み直す。
**このドキュメントは設計の出発点であり、安全・競技適合・性能を保証しない。未確認の項目は「未確認」と明記する。**

## 1. 方針

| 項目 | Rev A | Rev B |
|---|---|---|
| 目的 | ベンチ実証 | ロボット搭載(小型・安価) |
| 基板 | 1枚 315×235 mm | **2枚: キャパシタ基板 + 制御基板** |
| 実装 | 手配線・外付け多数(接触器4個、12V電源、外付けアルミ板抵抗) | **JLCPCBのSMT前提。基本部品/推奨部品を優先** |
| 公式CM01 | 未反映 | **経路に必ず入れる**(S187) |
| 電力段制御 | STM32のデジタル制御 | **B案: 専用制御IC + 軽いMCU** |
| 対象兵種 | — | 英雄・歩兵・哨兵で共通 |

## 2. 接続構成(2026年制作規範 図3-50 に基づく)

```
電源管理モジュール(Chassis出力) ─┐
無線充電受信端(任意) ────────────┤
                                  ▼
                           [制御基板 = 功率控制板(自作)]──→ 底盤給電
                                  │ XT30
                                  ▼
                        [CM01 公式管理モジュール] ──CAN(4pin)──→ 電源管理モジュール CAN1
                                  │ XT30(入力)
                                  ▼
                           [キャパシタ基板 = 超级电容模組(自作)]
```

- キャパシタ基板: セル直列、バランス回路、**電力ポート1つ(XT30)のみ**。MCUなし。
- 制御基板: 双方向DC-DC、保護、電流・電圧計測、CAN、MCU。
- CM01はCAN仕様が非公開のため、制御基板はCM01と通信しない。

## 3. 確認済みルール(2026年制作規範のスクショ p.14, p.96-98 で確認)

| 条項 | 内容 | Rev Bへの影響 |
|---|---|---|
| S5 | 英雄・歩兵・哨兵のみ。1台につき1組まで | 1組構成 |
| S6 | 公称エネルギー ≤ 2000 J、実測 ≤ 2200 J。E=½CU²(U=耐圧, C=容量) | 直列n個の公称 = n × ½CU²。容量公差を見込む |
| S7 | 底盤電力に関与しないChassis接続容量の合計 ≤ 10 mF | 制御基板の入出力コンデンサの扱いを要確認 |
| S184 | CM01のXT30はピーク・連続とも ≤ 15 A | 電容側電流制限はリップル込みで設計(例: リップル4Ap-pなら平均13A以下) |
| S185 | 満充電から1 V未満まで放電できること。異常な急降下は不合格 | 基板側に低電圧遮断を入れない |
| S186 | 検査用XT30メスを100 mm以上のケーブルで引き出す | CM01側の配線(基板外) |
| S187 | 英雄・歩兵・哨兵はCM01搭載必須 | 構成に反映済み |
| S189 | 電容組の給電経路は1系統のみ。図3-50どおり。他の回路に接続しない | **セルごとの監視配線を制御基板へ出さない** |

## 4. 他AI(GPT)調査由来・私は未確認

- ロボットの最大供給電圧 30 V(S94/S98/S113)。
- 底盤電力上限: 歩兵 75 W(血量優先)/90 W(電力優先)、哨兵・英雄 100 W。バッファ 60 J。※RMUL 3V3 の値。出場大会の規則で再確認すること。
- 裁判システムUART(115200 8N1): 0x0201 底盤電力上限、0x0202 バッファエネルギー(10 Hz)。2026年版は0x0202の先頭8バイトが予約。→ 底盤の実消費電力は自前で計測する。
- 条項番号がスクショ(S184〜S189)とGPT(S183〜S188)で1つずれている。**規則書の版を1つに固定すること。**

## 5. Rev B 設計入力(案)

- 共通兵種対応のため、底盤電力は最大100 Wを想定して設計し、上限はソフト設定で切替。
- 電容側電流: 平均 ≤ 15 A − リップル/2。電圧が低いほど電流で制限。
- バンク電圧 ≤ 30 V(設計上限。実際は耐圧とばらつきに余裕を持たせる)。
- **バンクの最大電圧をバス電圧下限より低くする案**(例: 3V 60F×7直列、定格21V・公称1890 J)なら、電力段は2スイッチの双方向降圧で足りる。バス電圧範囲(Rev A資料では22〜26 V)の確認と、バスが下限を割る場面の動作定義が前提。
- 保護: 過電流・過電圧・短絡をハードウェアで遮断できる構成を優先し、ファームのみに依存しない。
- バランス: キャパシタ基板内で完結するパッシブ方式。

## 6. 未決事項(決めるのは人)

1. バンク構成(セル品番・直列数)。容量公差と実測2200 J上限の余裕。
2. バス電圧範囲と、バンク電圧との関係(降圧のみで足りるか)。
3. 制御ICの選定(JLCPCBの在庫・価格を確認してから)。
4. 対象大会・兵種ごとの電力上限。
5. S7の解釈(制御基板の入出力コンデンサ)。
6. 規則書の版。
7. 通電前の試験手順(電流制限付き電源、ヒューズ、段階的な電圧上げ)。

## 7. 次のステップ

1. キャパシタ基板: セル候補とバランス方式の比較。
2. 制御基板: 制御IC候補の比較(JLCPCB在庫・価格、必要な外付け部品)。
3. ブロック図の確定 → 回路図(KiCad)。

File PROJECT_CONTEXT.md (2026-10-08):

# Firmware implementation — 2026-10-08

Current: Rev A STM32G474RET6 firmware source implemented; default SAFE_MONITOR_ONLY. Host logic tests and ARM builds are recorded in docs/firmware_validation.md. No flash, option-byte write, real PWM/contact actuation or energizing was performed. Hardware/CAD is unchanged. Calibration, control gains, timing, BQ physical behavior and power limits require bench measurement and human review before first flash/energizing.

Current guides: [firmware architecture](docs/firmware_architecture.md), [operation](docs/supercap_user_guide.md), [commissioning](docs/firmware_commissioning.md), [CAN protocol](docs/can_protocol.md), [tuning](docs/control_tuning.md), [flash setup](docs/firmware_flash_setup.md).

## Historical records (preserved)

# PCB routing complete — 2026-10-07

**Current: Prototype Rev A CAD routing complete.** KiCad10.0.6の正式PCBでnative未接続0、全DRC0 errors/0 warnings、schematic parity0、ERC0 errors/0 warningsを確認した。全331ネット／1524 net-assigned pad recordsの物理接続と、設計manifestの1478 pad/net assignmentsを照合済み。これはCAD接続・規則検証であり、製造リリース、通電許可、120 W性能、競技適合の承認ではない。

一般銅箔間隔0.20 mm、承認済み39 ICの同一部品内Pad/Pad0.15 mmを維持した。新たなDRC除外・No ERC・規則緩和はない。未コミットの`.kicad_pro`設定展開は保持し、functional commitに含めない。詳細は[配線完了記録](docs/pcb_routing_completion.md)を現在の情報源とする。以下は過去時点の記録として保存する。

## Historical records (preserved)

# PCB engineering authorized — 2026-10-04

ユーザーがsurge・OC遮断時間・fuse/接触器協調・熱・放電時間の実測前にPCB配置/配線へ進むことを明示承認した。[現行PCB記録](docs/pcb_rev_a.md)を優先する。未実測の項目はPrototype Assumptionとして保持し、製造/通電/性能保証にはしない。以下の「PCB未承認/開始しない」は過去時点の記録として残す。

## Historical records (preserved)

# Prototype Rev A — 2026-10-04 delegated decisions

ユーザーの委任に基づき、セル監視RAM設定・exact passive選定・外部ベンチ遮断アセンブリ・保護/熱/放電検証基準を[現行選定書](docs/rev_a_design_freeze.md)へ確定した。選定はPrototype Assumption、実測検証は未実施。平均cap電流の初期上限9.5 A、OC約12 A、目標遮断0.5 µs、各link bulk6×470 µF、precharge timeout3 s。12 A/120 Wは後続の検証目標として保持。PCB placement/通電は開始しない。以下の2026-10-03以前の未選定表示は経緯記録であり、この選定書が優先する。

# Prototype Rev A — current status

2026-10-03 JST。**Current: Prototype Rev A schematic only.** Task2 architectureはユーザー採用承認済み。実機条件未確認は[Prototype envelope](docs/prototype_rev_a_envelope.md)に明示した **ASSUMPTION — MUST VERIFY ON PROTOTYPE** として隔離し、詳細electrical schematicを作成した。部品/保護閾値はprototype候補で性能保証ではない。[現行review](docs/rev_a_schematic_review.md)と[pinout](docs/pinout.md)が現在の設計記録。PCB placement/routing、firmware、通電、120W使用許可、競技適合、Task4開始は未承認。以下の旧status/approval pending/skeleton-only記述はhistorical recordであり現在statusではない。

[Validation record](docs/rev_a_validation.md): ERC0/0;467 actual components; PCB unchanged. External interruption assembly and supercap monitor configuration remain unfinished.

## Historical records (preserved)

# Task 4 current status — placement gate未通過

2026-10-03 JST。Task 3 base428ad10を保持。重大TBDと詳細回路未実装のため添付Task 4 §1に従いplacement/outline/footprint/routingは行わない。[独立review](docs/task4_review.md)が現在status、[PCB方針](docs/task4_pcb_strategy.md)は提案、[検査結果](docs/task4_baseline.md)は既存skeleton限定。Task 5へ進まない。以下は過去Task記録。

---

# Task 3 current status

2026-10-03 JST。Task 2案はユーザー採用承認済み。実bus/surge・peak継続/間隔・ambient/coolingは未確定（ユーザー回答：不明）。承認範囲と詳細回路gateは[Task 3 review gate](docs/task3_review_gate.md)を優先する。Task 3は候補評価まで進行中、詳細回路未実装。以下のTask 2承認待ち表示は承認範囲についてhistorical record。

---

# Project context — Task 2

2026-10-03 JST。2026 RMUL、哨兵・歩兵・英雄・エンジニアをユーザー指定。S5によりEngineerへの競技底盤supercap assistは対象外。開催地/種目、battery/robot実bus/assist requirementはTBD。
Task1はmainの077fd5fまで、Task2はfeature/system-architecture。今回要求refinement、根拠付きproposal、energy/power計算、sensing/MCU/safety、同一KiCad project更新まで。詳細power stage/PCB/firmware/通電なし。
[requirements freeze](requirements.md)と[proposal](docs/task2_decisions.md)を最優先に読む。人間レビュー前の採用案はAssumption。cell数/Vcap/max current/peak power/topology/MCU/sensing/prechargeと全component定格を承認してから詳細回路へ進む。Task3自動開始禁止。

---

## Task 1 record (historical; Task 2 above takes precedence)

# Project context

更新: 2026-10-03 (Asia/Tokyo)。Task 1: 調査・要求・安全・構成・KiCad skeletonのみ。

RoboMasterロボット用スーパーキャパシタのエネルギーバッファを自作する。robot power busから充電し、必要時にrobotへ供給する。capacitor stateを監視し、charge/dischargeを制御し、CAN等でrobot controllerと通信し、安全状態を維持する。

## Evidence status

- **Confirmed**: ユーザーが要求した目的・Task 1 scope・人間レビューgate。これは検証済みハードウェア性能を意味しない。
- **Assumption**: 非絶縁の双方向power flow、STM32によるデジタル制御を比較の出発点とする。採用決定ではない。
- **TBD**: 対象大会・年・地域・ロボット種別、適用規則最新版、robot bus仕様、capacitor候補、全定格、topology、実装・試験。

要求は [requirements.md](requirements.md)、危険分析は [safety](docs/safety.md) と [FMEA](docs/fmea.md)。公式規則は版・条項・適用範囲を確認し、過年度値や他チームの実績値を本仕様に移さない。

## Human review gate

maximum bus voltage、capacitor maximum voltage、cell count、maximum charge/discharge current、maximum output power、converter topology、MOSFET定格、inductor定格、fuse定格、connector定格は人間レビューなしに確定しない。

Task 1で詳細MOSFET選定、gate driver回路、inductor sizing、switching frequency最適化、補償、PCB routing、高電流銅箔設計、firmware実装、物理prototype試験を行わない。Task 2へ自動移行しない。

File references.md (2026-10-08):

# References and provenance

## Rev A firmware sources (access 2026-10-08 JST)

| Source / author | Rights / version | Use / difference |
|---|---|---|
| [BQ76942 TRM / TI](https://www.ti.com/lit/ug/sluuby1b/sluuby1b.pdf) | SLUUBY1B; TI copyright; URL only | SPI CRC/pipeline, RAM checksum, cell mapping, FET/status commands; project-authored driver, physical timing/polarity still unmeasured |
| [RM0440 / ST](https://www.st.com/resource/en/reference_manual/dm00355726.pdf) | ST copyright; URL only | G474 timers/ADC/triggers/fault/boot options; project-authored initialization, no copied manual/PDF |
| [UM2570 / ST](https://www.st.com/resource/en/user_manual/um2570-description-of-stm32g4-hal-and-lowlayer-drivers--stmicroelectronics.pdf) | ST copyright; URL only | HAL/LL API behavior; no manual assets copied |
| [ST G4 HAL](https://github.com/STMicroelectronics/stm32g4xx-hal-driver/tree/v1.2.5) | BSD-3-Clause, v1.2.5 | External unmodified build dependency; not vendored/published here |
| [ST CMSIS device G4](https://github.com/STMicroelectronics/cmsis-device-g4/tree/v1.2.4) | Apache-2.0, v1.2.4 | External startup/system/register headers; not vendored |
| [Arm CMSIS5](https://github.com/ARM-software/CMSIS_5/tree/5.9.0) | Apache-2.0, 5.9.0 | External Cortex-M4 core headers; not vendored |

## Task 4 layout principles (access2026-10-03 JST)

| Source / author | Rights / use / difference |
|---|---|
| [SSZTAE5 Feb2017 / Vijay Choudhary, TI](https://www.ti.com/document-viewer/lit/html/SSZTAE5/GUID-1402DA8B-73DB-44B4-B203-A3AF307A6C45) | TI著作物、linkのみ。両port hotloop/dvdt/sense隔離の原理を参照。自作MCU/driver構成、layout未実装 |
| [SSZT533 Feb2019 / Youhao Xi, TI](https://www.ti.com/document-viewer/lit/html/SSZT533/GUID-8E8A4702-76CD-495F-A121-6F12027C6292) | TI著作物、linkのみ。gateとreturnの閉loop面積を参照。第三者画像/PCBデータをコピーしない |

## Task 3 manufacturer shortlist (2026-10-03 JST)

全てメーカー著作物、転載許諾は仮定せずURLと自作の比較・数値だけを記録。PDF/画像/schematic/PCBの公開repositoryコピーなし。利用目的は候補比較・計算で、メーカーreference回路の複製やvalidated設計の主張は行わない。

| Source / author | Revision / access | Use / difference from own design |
|---|---|---|
| [CSD18540Q5B / TI](https://www.ti.com/lit/ds/symlink/csd18540q5b.pdf) | SLPS488B Apr2017;2026-10-03 | RDS/Qg/Qrr/thermal候補根拠、own designのsurge/熱/PWM未確定 |
| [CSD18563Q5A / TI](https://www.ti.com/lit/ds/symlink/csd18563q5a.pdf) | SLPS444C Jan2016;2026-10-03 | 低Qg代替比較、同じdatasheet test条件を実動作としない |
| [UCC27282 / TI](https://www.ti.com/lit/ds/symlink/ucc27282.pdf) | SNVSAQ5B May2022;2026-10-03 | DRC EN/interlock/UVLO、独立HI/LI kill/disconnectが別途必要 |
| [UCC27211A / TI](https://www.ti.com/lit/ds/symlink/ucc27211a.pdf) | SLUSBL4D Jul2024;2026-10-03 | driver代替、外部EN/interlock要求はown design |
| [XAL1510 / Coilcraft](https://www.coilcraft.com/getmedia/cd1cef27-13f0-4568-8894-f7311475209b/xal1510.pdf) | Document947 revised05/04/26;2026-10-03 | 15/22µH DCR/Isat/Irms、DC bias/thermal適合は未確定 |
| [INA240 / TI](https://www.ti.com/lit/ds/symlink/ina240.pdf) | SBOS662C Dec2021;2026-10-03 | signed shunt amp、own designは別fast comparatorを要求 |
| [INA241A / TI product](https://www.ti.com/product/INA241A) | product page2026-10-03;datasheet版TBD | 高速代替比較のみ、PDF取得失敗につきpin/settling未照合 |

Accessed: **2026-10-03 JST**。外部ファイルのコピーなし。README/公開記事の限定的な調査で、schematic netlist/PCBを監査したものではない。
UnknownはTBD。以下のlicenseは対象sourceに限り、関連hardwareへの包括許諾とはしない。

| ID | Project / author / source URL | License / scope | 参考にした内容 | 自分の設計との違い |
|---|---|---|---|---|
| R1 | [RM2023-SuperCapacitor / HKUST ENTERPRIZE](https://github.com/hkustenterprize/RM2023-SuperCapacitor) / [BBS作者記事](https://bbs.robomaster.com/article/9452?source=8) | GitHub GPL-3.0表示。ただしBBSに隊間交流・非商用制限の記載があり整合TBD、再利用しない | 四switch双方向制御とcontrol/power分離の設計意図 | 本projectは独立fast trip・fault isolationを要求、定格は未決定 |
| R2 | [PSP_supercapacitor / Pacific Spirit・Great Lakes / wele0612](https://github.com/wele0612/PSP_supercapacitor) | repository GPL-3.0、文書CC-BY-SA表記(version TBD)、外部hardware scope TBD | 多相parallel、ADC基準とfirmware校正の一致 | 多相はまだ採用せず、校正不整合をsafety requirement化 |
| R3 | [SP_Ultra_CAP / Hebei University of Technology 山海Mas / Sirius-RX](https://github.com/Sirius-RX/SP_Ultra_CAP) | MIT表示、各assetへのscopeは再利用時確認 | single-board統合・mode切替・current calibration問題 | 必要telemetryと保護に限定し、UI/IMUを要求しない |
| R4 | [Electrical-System / PurdueRM](https://github.com/PurdueRM/Electrical-System) | rootで明示license未確認(TBD)、再利用不可として扱う | passive bankとSTM32 chargerの分割 | assistを含む双方向energy管理とshutdownを明示 |
| O1 | [RoboMaster公式hub / RMOC](https://bbs.robomaster.com/wiki/20204847) / [公式download](https://www.robomaster.com/zh-CN/resource/download/competition) | DJI著作物、転載しない | 適用規則の一次入口 | 本projectの数値確定は人間レビュー後 |
| O2 | [公式2026制作規則V1.3.0](https://bbs-web-static.robomaster.com/715e2519e5384666a5d13edda17c6b831770696773838/RoboMaster%202026%20%E6%9C%BA%E7%94%B2%E5%A4%A7%E5%B8%88%E9%AB%98%E6%A0%A1%E7%B3%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) / RMOC | ©2026 DJI、リンクのみ | S5–7、3.12、S184–189本文 | 最新版・対象への適用はTBD、規定値は部品定格でない |
| M1 | [STM32 migration AN5094 / STMicroelectronics](https://www.st.com/resource/en/application_note/an5094-migrating-between-stm32f334303-lines-and-stm32g431xxg474xxg491xx-microcontrollers-stmicroelectronics.pdf) | ST資料、リンクのみ | G474/F334のtimer/ADC/CAN比較 | exact MCU/package/pinsはTBD |
| M2 | [STM32F334 documentation / STMicroelectronics](https://www.st.com/en/microcontrollers-microprocessors/stm32f334/documentation.html) | ST資料、リンクのみ | DS9994/RM0364/errataへの入口 | 対象revisionの確認は選定時 |
| M3 | [STM32 digital power ecosystem / STMicroelectronics](https://www.st.com/content/st_com/ja/ecosystems/stm32-digital-power.html) | ST資料、リンクのみ | HRTIM/PWM同期制御の候補根拠 | evaluation boardの回路・定格を流用しない |

## Discovery-only pointers (not a specification authority)

- [2026 rule index](https://github.com/Fbnnkk/rm-battlescope/blob/main/docs/RMUC_2026_%E8%A7%84%E5%88%99%E4%B8%8E%E6%95%B0%E6%8D%AE%E7%B4%A2%E5%BC%95.md): 後続V2.0.0の存在を示す手がかりのみ。
- [CQU QIANLI resources](https://team.cquqian.li/museum/resources.html): V2.0.0制作規則、V2.2.0競技規則、2027資料の案内。PDF linkは404。これらの値を要求に使用しない。

調査は4チームの4設計で停止。R1が過去の他チーム設計から影響を受けているため完全な系譜独立ではないが、同一repositoryのfork4件ではない。R1とR2/R3の双方向案に対しR4の分離charger/bankを対比する。
BBSを入口として優先し、閲覧可能なGitHub作者資料で補完した。各sourceのauthor-reported performanceは独立検証していない。
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

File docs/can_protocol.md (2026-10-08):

# Rev A CAN protocol v1

Implementation: `firmware/controller/App/protocol.c`; FDCAN1 in Classic CAN, standard 11-bit IDs, 8 data bytes, 500 kbit/s, nominal sample point 80%. This is a project protocol, not a claimed RoboMaster referee protocol. Robot integration and bus ID allocation require review.

All frames: byte0 protocol version=1; byte1 sequence; byte7 CRC-8 polynomial 0x07, init0, no reflection/XOR, over bytes0–6. Multi-byte integers are little-endian. Receive filters accept command ID **0x501**. Extended IDs, RTR, FD frames and wrong lengths are rejected by the board layer/parser.

Command: byte2 opcode, byte3=0, bytes4–5 unsigned power in 0.1 W, byte6=0. Non-power commands require zero power. Accepted sequence advances by 1..127 modulo256; duplicate/backward/ambiguous sequences are rejected. A rejected command does not renew permission.
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

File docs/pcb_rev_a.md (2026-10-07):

# PCB routing complete — 2026-10-07

**Current: Prototype Rev A CAD routing complete.** KiCad10.0.6の正式PCBでnative未接続0、全DRC0 errors/0 warnings、schematic parity0、ERC0 errors/0 warningsを確認した。全331ネット／1524 net-assigned pad recordsの物理接続と、設計manifestの1478 pad/net assignmentsを照合済み。これはCAD接続・規則検証であり、製造リリース、通電許可、120 W性能、競技適合の承認ではない。

一般銅箔間隔0.20 mm、承認済み39 ICの同一部品内Pad/Pad0.15 mmを維持した。新たなDRC除外・No ERC・規則緩和はない。未コミットの`.kicad_pro`設定展開は保持し、functional commitに含めない。詳細は[配線完了記録](pcb_routing_completion.md)を現在の情報源とする。以下は過去時点の記録として保存する。

## Historical records (preserved)
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

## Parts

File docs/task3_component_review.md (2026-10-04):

# Prototype Rev A — 2026-10-04 delegated decisions

ユーザーの委任に基づき、セル監視RAM設定・exact passive選定・外部ベンチ遮断アセンブリ・保護/熱/放電検証基準を[現行選定書](rev_a_design_freeze.md)へ確定した。選定はPrototype Assumption、実測検証は未実施。平均cap電流の初期上限9.5 A、OC約12 A、目標遮断0.5 µs、各link bulk6×470 µF、precharge timeout3 s。12 A/120 Wは後続の検証目標として保持。PCB placement/通電は開始しない。以下の2026-10-03以前の未選定表示は経緯記録であり、この選定書が優先する。

# Prototype Rev A — current status

2026-10-03 JST。**Current: Prototype Rev A schematic only.** Task2 architectureはユーザー採用承認済み。実機条件未確認は[Prototype envelope](../docs/prototype_rev_a_envelope.md)に明示した **ASSUMPTION — MUST VERIFY ON PROTOTYPE** として隔離し、詳細electrical schematicを作成した。部品/保護閾値はprototype候補で性能保証ではない。[現行review](../docs/rev_a_schematic_review.md)と[pinout](../docs/pinout.md)が現在の設計記録。PCB placement/routing、firmware、通電、120W使用許可、競技適合、Task4開始は未承認。以下の旧status/approval pending/skeleton-only記述はhistorical recordであり現在statusではない。

## Rev A selection supplement

CSD18540Q5B / UCC27282DRCR / XAL1510-223MED at200kHz selected as prototype candidates. Fast fronts are INA293A1 pairs, not INA301 (40V absmax vs45.4V SMBJ28A clamp conflict). Detailed current review and pin checks are in rev_a_schematic_review.md / pinout.md; old candidate-only statements below are historical.12V driver vs10V Qg model difference remains explicit.

## Historical records (preserved)

# Task 3 component review — conditional shortlist

2026-10-03 JST。採用承認は[gate](task3_review_gate.md)。以下はメーカー一次資料からの候補比較であり、定格freeze・発注BOM・回路完成ではない。surge/peak duty/coolingはユーザー回答「不明」のため、第一候補も条件付き。

## MOSFET

| Candidate | Datasheet evidence at25°C,10 V gate | Tradeoff / conditional choice |
|---|---|---|
| TI CSD18540Q5B | 60 V, RDS max2.2 mΩ, Qg typ41/max53 nC, Qgd typ6.7 nC, Qrr typ145 nC at30 V/28 A/300 A/µs; SON5×6 mm | 第一比較候補。低RDSで大電流conduction有利、Qg/Qrrが大きい。Qg/Qrrのtest条件は実回路と異なる |
| TI CSD18563Q5A | 60 V, RDS max6.8 mΩ, Qg typ15/max20 nC, Qgd typ2.9 nC, Qrr typ63 nC at30 V/18 A/300 A/µs; SON5×6 mm | 低Qgでdriver負荷が小さいが大電流ではconduction増。周波数・duty・冷却で再比較 |

[CSD18540Q5B DS SLPS488B / Apr2017](https://www.ti.com/lit/ds/symlink/csd18540q5b.pdf) §§5.1–5.3はRθJC max0.8°C/W、RθJA max50°C/W(指定1in²/2oz銅箔)、minimum pad125°C/Wを区別する。package/siliconの大きなIDを基板のcontinuous許可値にしない。[CSD18563Q5A DS SLPS444C / Jan2016](https://www.ti.com/lit/ds/symlink/csd18563q5a.pdf) §§5.1–5.3と比較。熱・SOA・diode導通・avalancheの条件確認が必要。avalancheを定常surge吸収手段にしない。

RDSはmax25°Cを基にhot multiplier1.6を**感度仮定**として計算。温度の保証値ではない。switching時間40 nsも仮定で、DSのRG=0立上り時間を実機に流用しない。60 V候補の余裕はVDS実peak=bus/surge+Lstray di/dt+ringingで評価し、30 V競技上限との差だけで合格にしない。driver12 V案とRDS/Qgの10 V test条件の差も再計算する。symbol/footprint/pinは未実装・未照合。

## Gate drivers

| Candidate | Confirmed evidence | Suitability |
|---|---|---|
| UCC27282DRCR ×2 | 3 A halfbridge, VDD recommended5.5–16 V(nom12), input interlock, DRC10-pinだけEN、内部EN250 kΩ pull-down; EN disable typ1.5 µs | 第一比較候補。外部EN bias+killを追加。ENだけのfast OC停止は未保証。HS100 VとHB120 V absoluteを区別 |
| UCC27211ADRM ×2 | 3.7 A source/4.5 A sink, VDD8–17 V, UVLO8 V class、独立HI/LI、VSON8 | EN/interlockの追加外部設計が必要。出力電流の大きさだけで選定しない |

[UCC27282 SNVSAQ5B / May2022](https://www.ti.com/lit/ds/symlink/ucc27282.pdf) §§6.3,6.5,7.3.1, [UCC27211A SLUSBL4D / Jul2024](https://www.ti.com/lit/ds/symlink/ucc27211a.pdf) §§4–7を根拠とする。相互interlockはtimer deadtime設計の代用にならない。default OFFはEN/HI/LI external pull-down、MCU resetとaux UVLO、hardware latchで確保する要求。

OC comparator→latch→HI/LI強制LOW + timer fault、EN LOWを冗長経路とする案。入力killからgate-offまでの最大delay、blanking、comparator/common-mode、latch電源、MOSFET turnoffとdisconnect時間はTBD。driver stuck-highはこの経路でも止まらず両側DC interruptが必要。

bootstrapはCeff≥(Qg(max)+IHB·ton+leak·ton)/ΔV、DC bias/tolerance/UVLO marginを含む。Cの値は最大連続ON時間未確定のためTBD。4-switchの非switching-leg high-sideを100% ONする方式ではbootstrap refreshが必要で、常時ONを仮定しない。deadtime・gate resistor・GS抵抗・zener・DNI snubberは波形とfault budgetに基づき後で設計する。

## Inductor

| Candidate | Nominal / DCR max25°C | Isat / Irms25°C reference | Conditional use |
|---|---|---|---|
| XAL1510-223MED | 22 µH ±20%,16 mΩ | 18.7 A at30% L drop;10.5/14 A at20/40°C rise | 第一比較候補。ripple低減有利、12 A域でCu損失・温度上昇が課題 |
| XAL1510-153MED | 15 µH ±20%,12.4 mΩ | 23 A at30% L drop;13/18 A at20/40°C rise | 熱・saturation余裕を比較、ripple増加とのtradeoff |

[Coilcraft Document947 revised05/04/26](https://www.coilcraft.com/getmedia/cd1cef27-13f0-4568-8894-f7311475209b/xal1510.pdf) pp1–3。Irmsは指定温度上昇の参考値でabsolute maxではなくland/airflow依存。Isatはtyp25°Cの30%低下点。両方ともDC bias・温度curveを使い有効Lとhot saturationを確認しない限り採用確定しない。

計算はΔIL=Vlow(1−Vlow/Vhigh)/(L_eff fs)、IL_rms²=IL_avg²+ΔIL²/12。22 µHがtolerance−20%、さらに仮定bias−20%で14.08 µHになった場合、26 V bus/12 V open bank/12 Aでは100 kHzでripple4.344 A、ILpeak14.172 A、200 kHzで2.172 A/13.086 A。100 kHzならTask 2目標3 Aを超える。この数値はmodule端rippleとは同一ではない。100–200 kHzを維持し、L・PWM・link容量・OC latencyをまとめて再選定する。

## Current sensing review

第一比較候補INA240A1(cap/IL,gain20)、INA240A2(bus,gain50)。[SBOS662C / Dec2021](https://www.ti.com/lit/ds/symlink/ina240.pdf)はbidirectional、CM−4..80 V、VCC2.7..5.5 V、offset max25 µV、gain error max0.2%。400 kHz classでPWM settling/ADC apertureを確認する必要があり独立fast OC comparatorを内蔵しない。

代替[INA241A official product](https://www.ti.com/product/INA241A)はCM−5..110 V、1.1 MHz class、PWM rejectionあり。datasheet取得失敗のため版・full pin/settling/電源仕様の照合はTBDで、具体gain品番は確定しない。各群2候補で調査を停止する。

計算候補3 mΩ Kelvin shunt、Vref1.65 V、ADC3.3 V、出力使用域0.2–3.1 V。cap/IL gain20なら±24.17 A、20 Aで0.45–2.85 V、ideal12-bit13.43 mA/LSB。bus gain50なら±9.67 A、8 Aで0.45–2.85 V、5.37 mA/LSB。shuntは12 Aで0.432 W、IL ripple RMS分を追加。gain/shunt/ADC/reference誤差・hot drift・pulse overload・open/short faultは別budget、抵抗製品/定格/amp保証出力swingは未確定。amp rail到達は正常電流と区別してfault化する。

## Remaining detailed circuits

| Circuit | Next calculation / evidence needed before implementation |
|---|---|
| bus/cap divider | 実surge、ADC powered-off injection、STM32 acquisition/source impedance、R tolerance/temp、RC bandwidth。Task 2の0–36/27 Vは計算rangeで入力耐圧ではない |
| cell monitor/balance | 9S差動監視、open-wire、MCU非依存cell OV、電源断保護、tap保護、単一port規則適合。IC未選定 |
| NTC | MOSFET群/L/bank、NTC/Beta/精度、open/short判定、hotspot/lag、上限温度からerror budgetを引く。回路値TBD |
| aux | 12 V driver candidate +3.3 V logic案、Vin/surge、power sequence、rail budget、referee cut時backfeed防止。regulator未選定 |
| DC-link | capport ripple15 A適合、bulk ESR/ripple、ceramic effectiveC/DCbias、OV/surge/temperature、公式energyへの寄与を確認。製品/容量TBD |
| precharge | link容量、ΔV判定、許容起動時間、resistor pulse curve、bypass weld/open、reverse current isolation。RC感度計算は値の採用ではない |
| bleed/dump/service | 最大C/energy、要求時間・安全閾値、抵抗pulse/continuous、thermal inhibit、OFF時電源、voltage indication/rebound。抵抗値TBD |
| reverse/isolation/fuse | MOSFET bodydiode、両側source、DC fault currentとenergy、interrupt rating・fuse coordination。PWM OFFで絶縁できるとはしない |

## Loss accounting

[実行可能なモデル](../simulation/component_budget.py)と[生成結果](../simulation/component_results.md)を参照。半導体conduction、overlap、gate、L Cu、3shuntを別項目とする。core/Coss/Qrr/deadtime/connector/aux未算入なので小計は未算入損失がある参考値でありefficiency保証ではない。Task 2のeta lossへ小計を足すと二重計上になるため別モデルとして扱う。bank ESRは別で12 A時初期25.92 W、aging2倍なら51.84 W。peak秒数・繰返しと熱容量が必要。

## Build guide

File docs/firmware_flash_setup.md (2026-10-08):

# Rev A programming setup — 2026-10-08

Status: procedure only. No probe connection, flash write or option-byte write was performed. First flash requires human review of the exact PCB, firmware ELF, power isolation and this checklist.

1. Disconnect robot, capacitor bank and external contactor power. Independently verify absence of stored energy. A programmer can backfeed the 3.3 V rail; review probe supply/target-sense wiring first.
2. Review `docs/pinout.md`, U11 STM32G474RET6/LQFP64 and SWD connector orientation. Use SWDIO PA13, SWCLK PA14, NRST, GND and target voltage sense. Do not assume connector pin numbers from another board.
3. Read and archive existing option bytes with STM32CubeProgrammer. Do not run an automated option-byte script. PB8 is FDCAN RX and can idle HIGH; it must not select system boot.
4. Human-check `nSWBOOT0=0`, `nBOOT0=1` (software-controlled BOOT0 LOW / main Flash boot). Read the installed tool's decoded descriptions against STM32G474 RM0440; do not paste an undocumented packed register value.
5. Keep PG10 as reset input/output: `NRST_MODE=3`. Do not repurpose the physical NRST pin as GPIO. Preserve unrelated RDP, WRP, BOR and boot settings; separately review any required change.
6. Select the **SAFE_MONITOR_ONLY** artifact. Review map, vector table at 0x08000000, 512 KiB Flash, contiguous 96 KiB SRAM, defaults `verified=false`, `tuning_verified=false`, `commissioning_authorized=false`.
7. Only after explicit human approval, program and verify Flash. Reset initially with actuator/bank power physically disconnected. Record firmware revision, artifact hash and option-byte readback.

Debug halt is not energy isolation. Firmware contains no automatic option-byte programming or flash calibration writes. Do not disable external protection/watchdogs to make a debug session continue.

Sources: [STM32G4 RM0440](https://www.st.com/resource/en/reference_manual/dm00355726.pdf), [STM32G474 product documentation](https://www.st.com/en/microcontrollers-microprocessors/stm32g474re.html). Exact board pin nets remain authoritative.

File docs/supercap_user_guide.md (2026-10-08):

# Prototype Rev A の使い方

現在はfirmwareコードとCADの段階です。実機commissioningは未実施です。通常buildはSAFE_MONITOR_ONLYで、PWM・ARM・接触器・dumpを動かせません。以下は将来の操作手順であり、現時点の通電許可ではありません。

## 装置の役割

robot busから9Sスーパーキャパシタへ充電し、必要時に蓄積energyをbusへ返します。bus/bank電圧、双方向電流、温度、個別cellと保護状態を監視します。40 W充電、80 W assist、120 W peakは設計要求であり実測保証ではありません。低電圧・高温・電流限界では要求より小さい出力になります。

## 接続と起動前確認

実PCBのconnector識別は`docs/interfaces.md`、`docs/pinout.md`とschematicを確認してください。robot bus、9S bankとcell taps、CAN、SWD、UART、外部接触器/補助電源/保護アセンブリ、service放電経路は別系統です。記憶した別基板のpin番号で配線しないでください。CAN終端とGND接続をbus構成に合わせます。外部保護アセンブリなしで安全性を仮定しないでください。

起動前にpolarity、bank/全cell電圧、tap順、fuse、接触器/抵抗配線、締結、残留energy、firmware modeとcommit/hashを確認します。PWM OFFでもbody diodeから電流が流れ得ます。接触器feedbackはreserved diagnosticであり、LOW/HIGHだけで開閉済みと判定しません。

## 初回commissioning

auxiliary only → MCU → BQ → sensors → CAN/UART → 無energyでhardware fault → low-energy precharge → low-energy converterの順です。詳細のPhase0–11を`firmware_commissioning.md`でPASSしてから進みます。最初から22 V、fullbank、120 Wを使いません。今回これらの実機操作は行っていません。

## 通常起動・充電・assist

将来のレビュー済み運用ではPOWER ON → BOOT_SAFE → MONITOR_INIT → SELF_TEST → DISARMEDです。robotから有効なARMを送ると両側PRECHARGE、ΔV確認、bypass/抵抗切替、READYとなります。SELF_TEST PASSだけでは自動ARMしません。

CHARGEはREADY/STANDBYから0..40 Wの入力power要求を送ります。cell2.45 V normal ceilingへ近づくと充電を絞ります。ASSISTはREADY/STANDBYから0..120 Wを要求し、80 W nominalとpeak予算・9.5 A software cap limit等に従います。方向を変える時はSTANDBYを経由します。120 Wは1 s/30 sの仮定予算で、実機検証前に使用できる保証値ではありません。

robotは新しいsequenceのSTATUS/keepaliveを100 ms以内の間隔で送り続けます。250 ms失効でgate OFFとfault latchになります。CAN commandの形式・ID・単位は`can_protocol.md`を実装の正とします。SAFE buildではARM要求は拒否されます。

## shutdownとfault

SHUTDOWN/DISARMはgateを止め、電流減衰を確認して接触器要求を落とします。OFFはbankを放電したことを意味しません。通信断、BQ loss、温度/NTC異常、hardware faultはFAULT_LATCHEDとなります。原因を調べ、除去し、冷却後にexplicit REARM → SELF_TEST → DISARMED → 新しいARMです。通信や電源が戻っただけでは復帰しません。BQ_FAILEDは自動再設定せず、修理/確認後の安全なresetが必要です。

UART2は115200/8N1で `status`, `sensors`, `cells`, `temps`, `faults`, `bq status`, `can status`, `version` を表示します。`gate on`等の生出力commandはありません。LED消灯は放電証拠ではありません。telemetryのstate/fault、ADC/BQ/calibration validityを確認し、未校正値を実測精度の値と解釈しません。SOEは電圧二乗に基づくenergy割合でbattery SOCではありません。

## serviceと残留energy

permanent bleed、switched dump、独立電圧表示を使える構成ですが、dumpはdefault未許可で、SERVICEと別のreviewed permissionが必要です。hardware/BQ UV等の保護で途中停止し得るため、dumpだけで完全放電を保証しません。必要時はレビュー済み外部service dischargeを使います。

独立meterで **bankと両local link <1 V、各cell電圧の絶対値 <0.5 V、残留energy <4 J** を確認し、**2分間reboundを観察**します。cell逆転も確認します。nominal容量ではなく最大容量/不均衡も考慮してください。OFF、LED消灯、MCU停止だけでは安全な放電済みと判断できません。放電時間と抵抗温度は未実測です。

firmware更新は`firmware_flash_setup.md`に従い、電源・bank・接触器を隔離したうえで人間レビューを経て行います。option-byteを自動変更するコードはありません。初回flashと初回通電は別々の承認事項です。

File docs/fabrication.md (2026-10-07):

# PCB routing complete — 2026-10-07

**Current: Prototype Rev A CAD routing complete.** KiCad10.0.6の正式PCBでnative未接続0、全DRC0 errors/0 warnings、schematic parity0、ERC0 errors/0 warningsを確認した。全331ネット／1524 net-assigned pad recordsの物理接続と、設計manifestの1478 pad/net assignmentsを照合済み。これはCAD接続・規則検証であり、製造リリース、通電許可、120 W性能、競技適合の承認ではない。

一般銅箔間隔0.20 mm、承認済み39 ICの同一部品内Pad/Pad0.15 mmを維持した。新たなDRC除外・No ERC・規則緩和はない。未コミットの`.kicad_pro`設定展開は保持し、functional commitに含めない。詳細は[配線完了記録](pcb_routing_completion.md)を現在の情報源とする。以下は過去時点の記録として保存する。

## Historical records (preserved)

# Routing checkpoint — 2026-10-04

**Routing incomplete.** 保存したPCBは電力7ネットの全パッド接続と、局所GND/一部信号配線を追加したcheckpoint。native未接続 **610本**（239 nets）、寸法・間隔DRC **0 errors/0 warnings**、schematic parity0。元の935本から325本を解消したが、配線完成/製造/通電/性能保証は意味しない。

現在の結果と残りを[配線作業記録](pcb_routing_completion.md)で確認する。以下は以前の経緯を含む。

# Approved fine-pitch clearance — 2026-10-04

ユーザーが同一fine-pitch部品内のパッド間0.15 mm、その他0.20 mm以上を明示承認した。39個の対象ICに同一referenceのPad/Pad例外を設定し、一般銅箔間隔0.20 mmを明示維持した。projectのhard floor0.15 mmは例外を許容するためで、一般ruleを0.15 mmへ緩めてはいない。

独立DRCテスト6件PASS：対象内0.15 mmは許容、0.14 mmは検出、非対象/別部品/pad-to-trackの0.19 mmは検出、非対象0.20 mmは許容。現行PCBの寸法・間隔DRC0 errors/0 warnings、schematic parity0。未配線はCLI報告499件／全ratsnest935本のままで、配線完成や製造承認を意味しない。

以前の自動承認拒否と218件の違反記録は以下に履歴として保持する。

## Historical records before this approval

# Prototype Rev A fabrication status

**NOT RELEASED FOR FABRICATION.** Placement/routing work was authorized2026-10-04 without earlier hardware measurements. The actual PCB and [validation](pcb_rev_a_validation.md) remain engineering drafts.

- Proposed bench outline315×235 mm,nominal1.6 mm thickness,four copper layers. Copper70 um outer/35 um inner is a budget assumption;actual substrate/prepreg/copper weights are not a purchase specification.
- Verify fine-pitch package copper spacing,mask registration and stencil/paste/EP voids with the selected fabricator. Existing hard minimum0.20 mm conflicts with some0.15 mm library pads and has not been reduced.
- Drill targets include M3 clearance3.2 mm,wire lands2.0/0.9 mm,through vias0.6/0.3 mm. THT capacitance pitch5 mm and polarity,shunt4-terminal lands,driver EP and MCU/BQ pitch must be checked on final assembly drawings.
- Mount external contactors,fuses,DDR supply,bank/source tap resistors and HS25 chassis dump resistors separately with covers and strain relief. Solder wire lands are not blind-mate connectors.
- Review all power necks/return loops/via arrays,gate return/bootstraps,Kelvin routing,ADC noise coupling,hardware-kill fanout,test access,creepage/clearance and switched-node copper areas before a manufacturing release.
- Gerber,drill,assembly order,hardware energizing and finished robot enclosure are not generated or authorized by this CAD work.

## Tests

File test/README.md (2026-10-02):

# Verification plan

Task 1: 公開ファイル監査、Markdown link確認、KiCad load/ERCとskeleton構造確認。
実機試験はしていない。将来: enable float/reset/crash、hardware trip、ADC open/short/stuck、CAN timeout、precharge timeout、bus loss、放電後の再上昇を低energy条件から検証する。
requirement ID → procedure → acceptance value → measured result → reviewerのtraceabilityを維持する。閾値未承認の試験を合格としない。

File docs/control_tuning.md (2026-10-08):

# Rev A control tuning

Status: **PROTOTYPE_TUNING_REQUIRED**. No PWM waveform, plant response or sensor delay has been measured. Production defaults prohibit arming. This document specifies future bench work; none was performed in this task.

`firmware/controller/config/rev_a_config.c` owns PWM200 kHz, ADC phase6800 HRTIM ticks (1.25 us at170 MHz×32), deadtime34 ticks at selected fDTG (~200 ns), software cap/IL targets9.5 A, provisional fast IL trip11 A, power40/80/120 W, thermal thresholds, precharge3 s, peak1 s / repeat30 s. Values are assumptions and must be reviewed together with external~12 A OC. The fast software trip is secondary and cannot replace the independent comparator/latch.

`config/calibration_defaults.c` owns measured voltage/current gains and zero offsets, actual ADC reference, NTC R25/B, current-loop Kp/Ki, version/CRC and `verified`. Current shunt orientations differ: bus positive charging, cap positive assisting, IL positive charging. Do not invert a sign to hide a wiring error.

1. With no high-energy bank, verify complementary polarity, startup OFF and asynchronous PA12 shutdown with a scope. Measure gate delays/deadtime/body-diode conduction, then edit `deadtime_ticks`; verify at temperature and both current directions.
2. Sweep ADC phase away from switch edges and measure INA240 settling. ADC1 six ranks and ADC2 four ranks use12.5-cycle sample time at42.5 MHz; estimated complete sequences3.53/2.35 us. The phase must leave time before the next5 us period. Check DMA overrun and actual interrupt latency; do not infer a quiet point from the compiled tick value.
3. Record zero-current raw codes and reference voltage; fit divider/shunt gains with an independent calibrated meter. The100 kOhm drain loading is included in factory formulas. Check powered-off behavior independently. Validate NTC open/short and temperature offsets/lag before setting calibration verified and CRC.
4. Current PI is voltage-command PI with duty feedforward, anti-windup and signed IL. Initial Kp≈0.13823 V/A and Ki≈86.85 V/(A s) derive from22 uH, assumed1 kHz crossover and100 Hz zero: **PROVISIONAL CONTROL GAINS — BENCH TUNING REQUIRED**. Begin with reviewed smaller gains/current and verify both quadrants. Account for sensor/filter/computation delay, saturation, bootstrap limits and current ripple.
5. Supervisor computes power-to-current demand using measured voltage, nominal efficiency0.90 and feedforward duty; current slew is100 A/s. This is an initial power-management framework, not calibrated closed-loop power accuracy. Tune measured power behavior and assess whether an outer PI is needed before claiming target power regulation.
6. Charge is capped40 W input request and tapers near cell2.40–2.45 V. Assist80 W nominal/120 W request is bounded by cap current, IL, voltage, temperature and peak budget. Never raise a limit merely to satisfy a power request.
7. Verify thermal derating between warning60/60/45 C and stop65/65/50 C. Rearm requires FET/L<50 C and bank<40 C; invalid NTC is a fault. Model measured lag and hot spots before changing thresholds.

The fast ISR runs per ADC2 sample (~200 kHz); DWT records worst IRQ cycles and trips CONTROL_TRACKING if a powered session overruns one nominal850-cycle period. Measure actual timing and headroom; compiled code is not a timing proof. Main loop owns SPI/commands/supervisor/heartbeat. BQ transactions may delay slow-loop execution; log actual loop latency under errors and traffic.

No runtime calibration write command is provided. Rev A uses reviewed compiled defaults, version+CRC and validity flags; no high-frequency Flash writes or partially atomic persistence. Before enabling a non-SAFE build, update calibration, gains and explicit commissioning/tuning permissions through a reviewed commit; CAN cannot grant them. LOW_ENERGY_COMMISSIONING is not an automatic physical low-energy guarantee: use externally limited supply and disconnected/full-bank isolation.

`discharge_timeout_ms=2400000` is a provisional40 min SERVICE stop budget, not a measured discharge duration. Fresh CAN lease is required when dump is authorized. Monitor and hardware permission apply to dump; DISARM stops it. Tune/validate the external resistor and remaining energy independently.

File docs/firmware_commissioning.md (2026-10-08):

# Rev A commissioning checklist

All phases below are **NOT EXECUTED**. A FAIL or missing evidence prevents the next phase. Review exact hardware revision, firmware commit/hash, mode, calibrated instruments, supply limits and independent disconnect before each energized phase. Firmware tests alone do not authorize energizing.

|Phase|Checklist / PASS|FAIL / stop condition|
|---|---|---|
|0 no power review|[ ] CAD/BOM/pinout, polarity, body-diode paths, fuse/contactors, safe defaults, firmware build and tests reviewed; bank/links independently discharged|Any unexplained connection, rating or software discrepancy|
|1 programming/options|[ ] Human-approved SAFE artifact; SWD wiring; nSWBOOT0/nBOOT0/NRST_MODE readback; no actuator supply|Unexpected options/boot, probe backfeed, outputs asserted|
|2 3.3 V auxiliary only|[ ] Rail/startup/reset current and all requests/PWM LOW; no bank/contact power|Rail fault, reset loop, unexpected output|
|3 BQ/sensors|[ ] Cell simulator mapping1..8+10;39 entries readback/CRC; tap disconnect tests; DCHG/DDSG polarity; ADC/NTC ranges/invalid detection; calibration documented|CRC/config error, any tap fault not inhibited, wrong scaling/sign|
|4 CAN/UART|[ ] v1 parsing/scales/freshness; read-only CLI; timeout/replay/rearm tests|Unauthorized command, stale lease accepted, raw dangerous CLI|
|5 hardware fault without energy|[ ] PA12 forces PWM inactive before ISR; latch/rail/watchdog/reset tests; heartbeat stops on main stall|Software-only shutdown or unwanted restart|
|6 precharge low energy|[ ] Current-limited source; bothlink voltage/current behavior;ΔV<1 V stable;3 s timeout; stuck bypass/contact faults tested|Inrush, backfeed, reserved FB wrongly assumed contact position|
|7 gate waveforms without high-energy bank|[ ] Reviewed non-SAFE permissions; polarity/deadtime/bootstrap/ADC phase; fault response; ISR budget measured|Shoot-through, edge sampling, timing overrun, unexpected arm|
|8 low-voltage converter|[ ] External limited energy/current; signed IL loop bothdirections; conservative gains; body-diode/isolation behavior|Instability, current/sign fault, failed disconnect|
|9 gradual current increase|[ ] Logged ramp steps, current ripple, shunt/connector temperatures, externalOC response and fuse coordination|Trip threshold/delay uncertain, component stress, overrun|
|10 thermal validation|[ ] Worst ambient/airflow/pulse/repetition measured; thermal lag/derating/cooldown verified; discharge/rebound independently measured|Any limit not met or residual-energy indication unreliable|
|11 full envelope review|[ ] Human signs measured surge, OC delay, fuse/contactors, thermal/current/power, shutdown/service evidence and robot/rules compatibility|Unmeasured assumptions or legal/interface mismatch|

Do not begin at22 V/fullbank/120 W. External hardware protection and meter/disconnect remain required throughout. AEV14012 feedback inputs are reserved diagnostics, not proof of contact opening. Flash/update/debug instructions are in `firmware_flash_setup.md`; future authorization is required before performing them.

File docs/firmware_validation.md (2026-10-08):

# Firmware validation — 2026-10-08 JST

Scope: code/build/PC tests only, routing-complete hardware base `f38ec4f`; branch `feature/stm32-firmware-rev-a`. No flash, option-byte write, energizing, actual PWM, contactor actuation, bank/robot connection or physical testing.

## Confirmed software evidence

|Check|Result|
|---|---|
|ARM GCC12.3.1 / CubeIDE1.15.1; CMake3.25 / Ninja|All three modes build; project -Wall/-Wextra/-Werror; compiler/linker warnings0|
|SAFE_MONITOR_ONLY size|text34168,data100,bss12324 bytes; Flash/RAM fit linker512 KiB/96 KiB|
|LOW_ENERGY_COMMISSIONING size|text36736,data100,bss18004 bytes|
|POWER_STAGE_CONTROL size|text36736,data100,bss18004 bytes|
|SAFE linked symbol inspection|No HAL_HRTIM_WaveformOutputStart, malloc, free or _sbrk symbol; GPIO LOW and runtime veto also reviewed|
|Host GCC11.4 / WSL Ubuntu22.04|SAFE339 assertions; LOW363; POWER363; CTest3/3 PASS|
|ASan+UBSan non-PIE host build|3/3 PASS; -fsanitize=address,undefined -fno-omit-frame-pointer -fno-pie, linker-no-pie; no sanitizer finding|
|Cppcheck warning/performance/portability C11, App/config|0 findings|
|BQ profile generator --check|39 entries match JSON; widths/addresses/LE values/cell mask/policy checks PASS|
|Profile corruption/schema tests|6 checks PASS, including wrong part, value, length, duplicate address, OTP policy rejection|
|Native KiCad netlist contract|47 U11 physical pin/net assignments PASS; AF/ADC rank sentinels present|
|Hardware preservation|PCB SHA256 unchanged; pre-existing dirty kicad_pro SHA256 unchanged; no schematic/PCB edits staged|

Host tests cover legal/illegal transitions, fault latching/rearm, command CRC/ranges/replay/wrap/timeouts, mapping, SOE, NTC/scaling/calibration CRC, precharge total timeout, cooldown, peak transition bookkeeping, balance selection/settling eligibility, telemetry/CLI, and behavioral BQ initialization/CRC/readback/loss. Mock BQ behavior is an explicit model, not actual IC verification. Test-only calibration/tuning permissions do not alter production defaults.

ASan+UBSan PIE build first passed all modes, but a subsequent run stalled/repeated DEADLYSIGNAL without a useful code-location report. That run was stopped; root cause is not established. The separate non-PIE configuration above completed all modes. Do not report universal sanitizer/platform stability. CTest now has10 s per-test timeout. Existing WSL configuration warning `boot.generateResolvConf` was observed; no WSL/system settings were changed.

Local full build/test logs and external sources remain ignored. This public summary omits absolute user paths and does not include binaries, manufacturer PDFs, private netlist exports or third-party source files. Reproduction commands are in `firmware/controller/README.md`; pinned external licenses/commits are in its `Drivers/README.md`.

## Review observations / remaining measurements

- Hardware async PA12 fault precedes software; software error also clears gate/ARM/contact requests. Shared hardware input cannot uniquely identify OC; SW current guards and generic fault flags are distinguished in documentation.
- Exact ADC channel ranks, shunt signs and divider/100 kOhm drain loading follow the actual schematic. ISR/foreground ownership uses short critical sections; nested pending fault updates cannot lose bitmask changes. CPU timing and calibration accuracy remain unmeasured.
- Startup LOW precedes output-mode setup; default SAFE cannot assert actuators. Other modes still require reviewed calibration/tuning/commissioning flags. CAN alone cannot grant these flags.
- BQ RAM readback/CRC and mapping are implemented. DCHG/DDSG polarity, ALERT cause behavior, reset/status interpretation, open-wire tap coverage and SPI timing require a cell simulator. COW cycle observation is not proof of every tap connection. No OTP/FET test commands; FET_EN toggle is guarded by readback.
- Precharge has one3 s budget across phases; voltages/current/time determine acceptance. Reserved feedback levels do not establish contact position. Physical contactor delays, stuck/welded failure, resistor pulses and isolation/fuse coordination remain untested.
- Signed IL PI and power-demand framework are implemented, but initial gains, feedforward, efficiency, sample phase, deadtime, ripple, measured power accuracy and200 kHz IRQ budget are **PROTOTYPE_TUNING_REQUIRED**.
- Charge40 W/assist80 W/peak120 W are requests, not demonstrated power. Initial cap/IL9.5 A limits and thermal thresholds are conservative software targets, not verified operating boundaries. Peak1 s/30 s and thermal lag/ambient/cooling require review and measurement.
- Service dump is separately gated/default forbidden; BQ/hardware UV may stop it before discharge completes. Independent service discharge/meter and2 min rebound observation are necessary. No claim of guaranteed discharge time or energy isolation.

Before first flash: review pinout/options/SWD/backfeed, SAFE artifact/hash, dependency revisions and GPIO/peripheral setup. Before first energizing: complete commissioning phases and approve external protections, waveform/timing, calibrated sensors, surge/OC/fuse/contactors, thermal and service measurements. No hardware permission is implied by passing these software tests.

CAN queue entries carry ISR receive timestamps. Expired queued commands cannot become fresh through delayed foreground processing; accepted leases retain their receive timestamp. Additional boundary tests cover this behavior.

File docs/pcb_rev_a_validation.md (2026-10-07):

# PCB routing complete — 2026-10-07

**Current: Prototype Rev A CAD routing complete.** KiCad10.0.6の正式PCBでnative未接続0、全DRC0 errors/0 warnings、schematic parity0、ERC0 errors/0 warningsを確認した。全331ネット／1524 net-assigned pad recordsの物理接続と、設計manifestの1478 pad/net assignmentsを照合済み。これはCAD接続・規則検証であり、製造リリース、通電許可、120 W性能、競技適合の承認ではない。

一般銅箔間隔0.20 mm、承認済み39 ICの同一部品内Pad/Pad0.15 mmを維持した。新たなDRC除外・No ERC・規則緩和はない。未コミットの`.kicad_pro`設定展開は保持し、functional commitに含めない。詳細は[配線完了記録](pcb_routing_completion.md)を現在の情報源とする。以下は過去時点の記録として保存する。

## Historical records (preserved)

# Routing checkpoint — 2026-10-04

**Routing incomplete.** 保存したPCBは電力7ネットの全パッド接続と、局所GND/一部信号配線を追加したcheckpoint。native未接続 **610本**（239 nets）、寸法・間隔DRC **0 errors/0 warnings**、schematic parity0。元の935本から325本を解消したが、配線完成/製造/通電/性能保証は意味しない。

現在の結果と残りを[配線作業記録](pcb_routing_completion.md)で確認する。以下は以前の経緯を含む。

# Approved fine-pitch clearance — 2026-10-04

ユーザーが同一fine-pitch部品内のパッド間0.15 mm、その他0.20 mm以上を明示承認した。39個の対象ICに同一referenceのPad/Pad例外を設定し、一般銅箔間隔0.20 mmを明示維持した。projectのhard floor0.15 mmは例外を許容するためで、一般ruleを0.15 mmへ緩めてはいない。

独立DRCテスト6件PASS：対象内0.15 mmは許容、0.14 mmは検出、非対象/別部品/pad-to-trackの0.19 mmは検出、非対象0.20 mmは許容。現行PCBの寸法・間隔DRC0 errors/0 warnings、schematic parity0。未配線はCLI報告499件／全ratsnest935本のままで、配線完成や製造承認を意味しない。

以前の自動承認拒否と218件の違反記録は以下に履歴として保持する。

## Historical records before this approval

# PCB Rev A validation record

2026-10-04 JST. PCB placement/routing authorized by the user despite unmeasured hardware conditions. Current routing and DRC counts are populated after actual session import and CLI DRC;do not infer completed routing from the board outline or render.

## Confirmed CAD checks

- Generated PCB contains481 board electrical footprints plus four mounting holes;46 external schematic components remain offboard and32 explicit boundary lands were added.
- KiCad-exported board netlist:481 components,331 nets,1410 pin/net matches. Independent protection logic checks27 inhibit inputs plus reset/unarmed/contact reclose/four PWM outputs.
- Existing energy/component model tests:8 passed. Existing major-component land geometry checks passed;these do not validate the PCB assembly process.
- Placement review removed courtyard/copper collisions outside the fine-pitch rule conflict;schematic parity was0 in the last placement check.
- Existing0.20 mm project hard minimum is retained. Fine-pitch pad spacings0.15 mm yield218 errors before routing. No ERC/DRC markers or new exclusions hide them.
- Full-board top render inspected:block regions and external interface separation exist. Gate/SW/current return quality needs close-up routed review.

## Unmeasured and not accepted as performance

Surge/regen,ripple/current recovery,OC total latency,fuse/contactor coordination,thermal rise,bleed/dump time,inductor bias L,full-power current and cell configuration programming remain unmeasured. User permission enables CAD progression;it does not turn their modelled targets into observations.

## Tool limits

Offline Freerouting2.4.1/Java25 is attempted with analytics/API/MCP disabled. An initial fanout pre-pass was stopped after slow exploration;the second pass also ran too long without producing a session. The final attempt is capped at five minutes and one pass. The actual exported session,if produced,is imported and checked rather than called complete. No further repeated attempts are made in this run if it leaves missing connections.

User `.kicad_pro` settings remain outside functional commits. KiCad may expand configuration while loading/exporting;existing settings are not replaced with repository HEAD. The original minimum0.20 mm remains unchanged.

## Final CAD outcome

Actual KiCad10.0.6 session import and final check:481 electrical footprints,4 mounting holes,929 track objects,213 via objects,2 filled GND zones,5 In1.Cu switch keepouts. PCB-to-manifest1478 pad/net matches;schematic parity0. **ERC0 errors/0 warnings. DRC218 errors/0 warnings.** All218 current DRC violations are fine-pitch clearance conflicts with the existing0.20 mm rule;no placement collisions or parity errors remain in the reported check.

**Routing is incomplete.** CLI DRC JSON contains499 missing-connection report items;the full KiCad connectivity/ratsnest count is **935 unconnected edges**. Do not equate the shorter CLI list with the full missing-connection count. Freerouting itself ended its bounded pass with1008 unresolved items;its definitions and pre-top-return geometry differ from the final native check.

Machine-readable original audit results are [pcb_rev_a_results.json](../simulation/pcb_rev_a_results.json). Some power nets remain entirely unconnected (`CAP_LINK_IN`,`SW_NODE_B`);some autogenerated SW routing uses In2.Cu and narrows to1.0268 mm. That is **not accepted** as a high-current layout. Kelvin paths use vias and currently carve the reference layer;they require manual paired/local rerouting. The gate loops,auxiliary supply decoupling,hardware-kill routing and return geometry need close-up review and completion. The saved board is a placement/partial-route checkpoint,not a finished PCB.

The final local F.Cu ground return connects bulk/low-side ground geometry and reduces native missing edges after the timeout result. It does not prove low loop inductance or current capacity. A final top render was inspected;gross body placement is separated,but the remaining power/sense wiring prevents manufacturing release.

## Next CAD work

1. Resolve the specific fine-pitch clearance/process rule decision without reducing unrelated power clearances;automatic approval review rejected the global minimum change.
2. Manually complete both commutation loops,SW/inductor path and port shunts with appropriate top/bottom copper and parallel-via arrays;remove/replace only the newly generated provisional inner-layer SW routes when doing so.
3. Complete short,paired Kelvin/driver/bootstrap/decoupling and fault paths,then remaining control/CAN/harness routing. Keep the reference layer continuous where possible.
4. Refill zones,check all935 native unconnected edges,run full DRC and schematic parity,review copper necks/return currents and inspect layer plots before a manufacturing decision.

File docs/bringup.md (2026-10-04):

# PCB engineering authorized — 2026-10-04

ユーザーがsurge・OC遮断時間・fuse/接触器協調・熱・放電時間の実測前にPCB配置/配線へ進むことを明示承認した。[現行PCB記録](pcb_rev_a.md)を優先する。未実測の項目はPrototype Assumptionとして保持し、製造/通電/性能保証にはしない。以下の「PCB未承認/開始しない」は過去時点の記録として残す。

## Historical records (preserved)

# Prototype Rev A — 2026-10-04 delegated decisions

ユーザーの委任に基づき、セル監視RAM設定・exact passive選定・外部ベンチ遮断アセンブリ・保護/熱/放電検証基準を[現行選定書](rev_a_design_freeze.md)へ確定した。選定はPrototype Assumption、実測検証は未実施。平均cap電流の初期上限9.5 A、OC約12 A、目標遮断0.5 µs、各link bulk6×470 µF、precharge timeout3 s。12 A/120 Wは後続の検証目標として保持。PCB placement/通電は開始しない。以下の2026-10-03以前の未選定表示は経緯記録であり、この選定書が優先する。

# Prototype Rev A — current status

2026-10-03 JST。**Current: Prototype Rev A schematic only.** Task2 architectureはユーザー採用承認済み。実機条件未確認は[Prototype envelope](../docs/prototype_rev_a_envelope.md)に明示した **ASSUMPTION — MUST VERIFY ON PROTOTYPE** として隔離し、詳細electrical schematicを作成した。部品/保護閾値はprototype候補で性能保証ではない。[現行review](../docs/rev_a_schematic_review.md)と[pinout](../docs/pinout.md)が現在の設計記録。PCB placement/routing、firmware、通電、120W使用許可、競技適合、Task4開始は未承認。以下の旧status/approval pending/skeleton-only記述はhistorical recordであり現在statusではない。

## Rev A gate before energizing

1. Independent schematic/package/land review; inspect selected exact passives/lands,source-side tap assembly,external power/fuses/contacts and required interruption tests against rev_a_design_freeze.md.
2. BQ supercap profile/readback/power-cycle/protection mapping and MCU BOOT0/reset options review. No gate arm with unprovisioned monitor.
3. Approve current-limited containment plan and independent bank/service isolation; OFF/LED dark never prove discharged.
4. Only after approval: staged auxiliary/low-energy fault tests, analog off-injection, bootstrap/ringing, actual trip latency/current excursion, precharge/dump and thermal characterization. Then review measured full-power/duty/competition envelope separately.

No tests in this list were physically performed. ERC/netlist/calculation results are not energizing authorization.

## Historical records (preserved)

# Task 4 measurement access plan — no energization

scope protective-earth ground clipをhigh-side gate/source、SW_NODE、bankのfloating pointへ無確認で接続しない。scopeのearthを外してfloating測定しない。rated differential probeまたは適切にisolatedされたmeasurement systemを使用し、differential/common-mode電圧、transient、bandwidth、probe spacingを確認する。VGSはgateとそのsource間で測定する。

bank未接続・低energyでfixture/ground/probe接続を確認し、原則deenergized状態でprobeを固定、独立meterで残留電圧とreboundを確認する。loopを短くするためのprobe padも指やground clipでshortしにくくする。[PCB方針](task4_pcb_strategy.md)のtestpointは未配置。現在回路/placement gate未通過につき通電許可ではない。

---

# Task 2 validation plan

今回通電なし。Task3承認後、current-limited/low-energy sourceでsensor calibration、ADC/PWM窓/latency、external comparator/kill、reset/boot/debug halt、cell OV/open-wire、precharge welded/open、referee cutoff、CAN stale、dump thermal/断線/reboundを段階検証する。
公式module peak15 Aのscopeとwaveform、fault interruption/energy let-throughを測定。cap公差/ESR/thermal/lifetimeと実usable energyを測定。実prototype結果なしにsafe/working/validatedと表現しない。
計算5 checksはunit/analytic runtime/both-direction power balance/current clamp/energy conservationを対象、circuit approvalではない。

---

## Task 1 record (historical; Task 2 above takes precedence)

# Future bringup gates

Task 1で実機試験なし。この手順は将来計画で、通電許可ではない。

1. 適用規則・robot envelope・capacitor datasheet・全limitを人間承認。schematic pin/rating/thermal/ERC、PCB DRCをreview。
2. bank未接続・power stage無効でauxだけをcurrent-limited sourceから起動。enable float/reset/brownout/debug haltがOFFであることを測定。
3. ADC/reference/calibrationを既知signalで確認。sensor open/short/stuckと独立tripをenergyなしで検証。
4. small-energy代替loadでprechargeとshutdown、timeout、CAN loss、fault latch、explicit rearmを確認。
5. approved limits下でconverter directionを個別確認。differential probeと測定器common groundによる短絡を防ぐ。
6. fault actionが証明された後にbank/energy/currentを段階的に増加。各段階でthermal、ripple、trip energyを記録。
7. robot統合は公式module接続・計測点・rule complianceの確認後。service dischargeとreboundを毎回確認。

合格条件の数値・probe rating・test fixture・緊急遮断・放電toolはTBD。
unresolved limit、failed trip、sensor不整合、未確認residual voltageがあれば次段階へ進まない。

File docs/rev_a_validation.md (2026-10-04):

# PCB engineering authorized — 2026-10-04

ユーザーがsurge・OC遮断時間・fuse/接触器協調・熱・放電時間の実測前にPCB配置/配線へ進むことを明示承認した。[現行PCB記録](pcb_rev_a.md)を優先する。未実測の項目はPrototype Assumptionとして保持し、製造/通電/性能保証にはしない。以下の「PCB未承認/開始しない」は過去時点の記録として残す。

## Historical records (preserved)

# Prototype Rev A — 2026-10-04 selection validation

Engineering selection is delegated;[current design freeze](rev_a_design_freeze.md) and [RAM profile](../firmware/config/bq76942_rev_a.json) supersede previous unselected-component gates. **No physical measurement,hardware programming,firmware,PCB placement or energizing was performed.**

| Check | Current result | Limit |
|---|---|---|
| KiCad10.0.6 ERC,final selected schematic |**Errors0 / Warnings0** |Existing four rule exclusions unchanged;no No-ERC markers |
| Actual exported netlist |495 non-flag components,343 nets,1504 intended pin/net entries |507 instances including12 flags;not an empty export |
| Fault logic |27 independent inhibit drops,unarmed/reset,four PWM kills/contact reclosure prevention PASS |Boolean logic only;0.5us physical clearing requirement UNPROVEN |
| Footprint pad audit |All assigned pad sets match;46 deliberate external components/interfaces without PCB land |External bank9cells,tap resistors,contactors/fuses/SSR/DDR/manual/service assembly are not onboard placement |
| Key geometry audit |WSK3mR T2.21 power/Kelvin dimensions,bulk5mm pitch,MCU/BQ0.5mm pitch,driver main EP PASS |Does not establish paste,clearance,tolerance,thermal or manufacturing readiness |
| Cell profile |39 RAM entries,widths/little-endian,mask0x02FF,SPI CRC,active-low-fault polarity,protection mapping/quantization PASS |Offline check,not live readback;FET_INIT_OFF/CP disable operation must be tested |
| Physics |8 existing tests PASS;new RC/energy/ripple/OC-bound/current-corner assertions PASS |η90%,ESR,Lbias,hotRDS andswitching assumptions;no switching/thermal guarantee |
| Publication |Original prose/code/MPNs/symbols/manifest only;manufacturer source PDFs/images ignored |No copied third-party assets;project license remains owner TBD |
| User settings / PCB |Original SHA256 values below retained |.kicad_pro remains unstaged;empty PCB unchanged |

Manual review:source/bank manual switches are not fault breakers;AEV contacts need fuse-clearing-before-separation verification at currents exceeding rated reverse interruption. DDR/coil branch has independent voltage windows. AQZ precharge off path is AC/DC;SSR and AEV devices must not be assigned invented auxiliary contacts. Header feedback pins are diagnostic interfaces;ADC progression/current observations and external isolation checks must establish actual behavior. DCHG/DDSG permits are healthy HIGH using0xA6;unconfigured/partial-power states remain startup inhibits. Source-side tap resistors are now actual external schematic elements. Service dump is independent of MCU auxiliary power. All six previously reviewed body-diode/failure conditions remain physical tests,not solved by ERC.

Corrections:ATOF32V label replaced withMINI99758V and matching58V holder;AEV low-load precharge replaced withAQZ;separate DDR actuator supply and voltage windows added;coil freewheel replaced by bidirectional suppression;bulk ripple led to6capacitors/link and3s timeout;WSK3mR land corrected fromT1.19 toT2.21;E96 feedback now909k/174k (~12.108/3.288V);OC reduced to~12A andinitial average cap limit9.5A;monitor CP tied BAT and39-entry supercap RAM profile added. Historical12A design-goal sensitivity rows remain explicitly labeled as future-goal calculations.

HS heatsink PDF retrieval returned403 in bounded attempts;manufacturer product/mechanical page retained,malformed web electrical table not treated as a verified thermal-rating table. Exact passive suffix inventory is a procurement check. Physical SOA/surge/ringing,OC delay/error/Lmin,contact/fuse/harness interruption,power sequencing,ADC off injection,monitor/tap fault tests,continuous/pulsed heat anddischarge/rebound remain unrun. **Task4 remains closed.**

## Historical validation record — 2026-10-03

# Prototype Rev A validation record

2026-10-03 JST, schematic-only review. No physical prototype test, firmware execution, PCB placement, DRC change or performance acceptance.

| Check | Result | Scope / limits |
|---|---|---|
| KiCad10.0.6 schematic load / PDF export |15 pages, original package-box symbols and label-connected electrical wires |Hierarchy + representative auxiliary/controller drawings inspected; every schematic pin/net audited by export. Does not certify readability of every pin at full-sheet scale or dynamic operation. |
| ERC, report2026-10-03T20:15:57 |**Errors0, Warnings0** |467 actual non-flag components; not an empty skeleton. No No-ERC markers. Explicit unused pins use NC. |
| Existing project rule exclusions |global label once / four-point junction / SPICE model / footprint-filter mismatch ignored |Preexisting KiCad setting expansion preserved; no settings altered to suppress violations. Default-excluded checks are disclosed; netlist audit adds connectivity/pad-number review. |
| Real KiCad exported netlist |467 components,329 nets,1440 pin/net entries matched to original manifest |Rejects empty export, duplicate references and disconnected intended global nets. |
| Protection logic audit |25 independent inhibit inputs, unarmed/reset, four PWM outputs and contact permit |Boolean topology only, no analog response/latency/metastability/partial-power guarantee. Comparator thresholds are provisional. |
| Candidate footprint audit |All assigned library footprint pad sets match original symbol pin sets |22 external/candidate components deliberately have no footprint. Physical dimensions/tolerances, exact passive products, thermal lands and assembly orientation remain human-review gates. |
| Calculation tests |8 existing physics tests PASS |SI units, power/energy conservation, RC energy, ripple scaling, RMS/loss accounting, current limits and integration convergence; not switching simulation. New40W charge-corner report also asserts power conservation. |
| Publication audit |No detected secret/private-email/broken local links or unexpected candidate file types |Original project symbols/JSON/code only. No manufacturer PDFs/images or copied external schematic/PCB added; PDFs used locally are ignored. Manual provenance review completed for added original files; license grant for project still owner TBD. |
| User local configuration |.kicad_pro SHA256 F57C810156A5CC7BCFA1870017D52E1A7A21E563FB546BA8B99A5B5D11F136BB |Unchanged from start of this task, remains unstaged. |
| PCB |SHA256 B82172E9D8465485C0742FFB5424F7B47D347219CB7DAEC1D8A3D129AD94B657 |Unchanged empty board. No placement/routing/zone/outline updates. |

## Review corrections made

- Initial malformed generated instance nesting caused empty KiCad loads; those initial ERC results were rejected. Strict parsing/component-count checks and real export audit now prevent that false pass.
- Off-grid wires/labels and missing diagnostic endpoints were corrected, not hidden by No-ERC.
- Fault-clear logic pin assignment was corrected and tested with independent inhibit drops.
- INA30140V absolute input limit conflicted with TVS45.4V rated clamp; replaced port fast front ends with already selected INA293 plus external comparator windows.
- TMUX powered-off protection is3.6V, not the powered-on5.5V input range.100k drain replaced1M so2µA max off leakage gives0.2V estimate; loaded-divider/NTC arithmetic updated.
- Initial1.8V BQ MISO needs level translation; added bank-powered SN74LV1T34 and rail-qualified SPI switches.
- DCU logic packages use2.3x2mm/0.5mm pitch, not DGK3x3mm/0.65mm; corrected candidate footprints after package-dimension review.
- Contact commands now require latched permit, preventing automatic contact reclosure merely when fault inputs recover.

## Release blockers and next review

The schematic is reviewable but is not a fabrication/energizing release. Independently review original symbols, datasheet terminals, candidate land geometry, all body-diode paths and the shared-fault analysis. Complete external source/bank interruption assembly (actuator supply/coil budget/fuse coordination/manual disconnect/source tap protection), exact local capacitors/passives, BQ supercap provisioning/readback and MCU boot/reset configuration. Only after a reviewed low-energy test plan should surge/ringing, bootstrap, shutdown excursion, power-off injection, thermal duty and discharge/rebound be measured. **Task4 remains closed.**

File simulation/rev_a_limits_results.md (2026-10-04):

# Rev A selected protection / assembly limits

**ASSUMPTION — MUST VERIFY ON PROTOTYPE.** Calculations establish required test criteria, not shutdown, temperature or surge capability.

- Six EEUFR1J471/link: 2820.0uF nominal; 3388.8uF worst including ceramic tolerance.100R1% t95 worst=1.0254s; energy at26V=1.1454J. Startup timeout3s,delta-V<1V.
- Bulk ripple bound IL/2=6Arms at12A:6parallel and1.3sharing factor gives1.3Arms/cap vs1.995Arms rating at100kHz.20% ripple derating target; verify200kHz multiplier and actual ripple/temperature.
- OC divider35.7k/10k,3.288V,gain20,3mR: nominal 11.99125A. Provisional±7% budget; measured actual threshold must fit this interval.
- Required clearing delay<=0.5us, Vfault<=48V, measured L>=14.08uH through15A: peak bound 14.5352A. Simple dI/dt bound excludes shoot-through/local short/saturation; these need fuse/source interruption. This demanding latency is UNPROVEN; failure requires redesign or tighter current envelope.
- Initial cap average limit9.5A;12A remains eventual design goal. No operation is enabled by this offline model.

| Bus / rest cap V | Requested / delivered W | Cap A | IL peak A | Partial board loss W |
|---|---|---|---|---|
| 22/12 |120/87.980 |9.500 |10.472 |5.171 |
| 22/22.05 |120/120.000 |6.379 |6.564 |3.044 |
| 26/12 |120/87.980 |9.500 |10.604 |5.464 |
| 26/22.05 |120/120.000 |6.379 |7.107 |3.227 |

- Four AEV14012 coils: max planning current 1.5532A,12V power 18.638W. Reserve24W output including electronics; DDR-60L-12 input planning29W at83% efficiency. Referee-point total charge budget=40W+29W+2Wboard aux=71W planning ceiling,not a measured total or rule allowance.
- MINI997 typical melting I2t10A93/15A270/5A25 A2s cannot be used as guaranteed maximum clearing energy. No semiconductor protection assertion from these values.
- Dump HS25 100R F(+1%),bank+30%C: time22.05->1V=2256.400s (37.607min); bank energy removed=1752.120J. Permanent bleed ignored here conservatively.40min acceptance target includes contact/path testing; imbalance and rebound separately checked.
- Service condition: bank AND both local links<1V,every cell magnitude<0.5V,2min rebound check,total residual energy<4J,source isolated and independent meter check. This is a delegated prototype procedure target,not demonstrated safe-service capability.
- Thermal criteria: ambient<=40C/open bench;software FET/L65C and bank50C stop,hardware backup≈69.5/53.7C. Verify hotspot-to-junction/winding lag;target FET junction<100C,winding<90C,bank<55C,connectors<60C. No continuous thermal power claimed.

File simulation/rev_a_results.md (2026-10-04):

Current selection limits/assembly results are in rev_a_limits_results.md;12A rows below retain the accepted future design goal.

# Prototype Rev A selected-candidate calculations

ASSUMPTION — MUST VERIFY ON PROTOTYPE. CSD18540Q5B, XAL1510-223MED22uH,
WSK25123L000FEA3mR; 180/200kHz. CSD18563Q5A /15uH alternatives remain in component_results.md.
Same eta0.9, ESR0.18ohm, L tolerance0.8*bias0.8, hotRDS factor1.6, winding80C, tr+tf40ns.
Driver12V; Qg53nC measured at10V reused as a LOWER-FIDELITY assumption, not a12V bound.
Subtotal excludes core/Coss/Qrr/deadtime/aux/connector and bank ESR; no efficiency guarantee.
Model is single-active-leg CCM; overlap/equal-rail modulation, startup and fault not modeled.

| fs kHz | bus / rest cap V | request W | delivered W | cap A | bus A | IL RMS / peak A | ripple App | loss subtotal W |
|---|---|---|---|---|---|---|---|---|
| 180 | 22/12 | 80 | 76.032 | 8.000 | 3.456 | 8.024/9.083 | 2.167 | 3.852 |
| 180 | 22/12 | 120 | 106.272 | 12.000 | 4.831 | 12.016/13.073 | 2.146 | 7.120 |
| 180 | 22/22.05 | 80 | 80.000 | 4.173 | 3.636 | 4.174/4.307 | 0.268 | 1.725 |
| 180 | 22/22.05 | 120 | 120.000 | 6.379 | 5.455 | 6.380/6.585 | 0.412 | 2.880 |
| 180 | 26/12 | 80 | 76.032 | 8.000 | 2.924 | 8.032/9.237 | 2.474 | 4.076 |
| 180 | 26/12 | 120 | 106.272 | 12.000 | 4.087 | 12.020/13.207 | 2.413 | 7.449 |
| 180 | 26/22.05 | 80 | 80.000 | 4.173 | 3.077 | 4.196/4.933 | 1.520 | 1.839 |
| 180 | 26/22.05 | 120 | 120.000 | 6.379 | 4.615 | 6.396/7.188 | 1.617 | 3.045 |
| 200 | 22/12 | 80 | 76.032 | 8.000 | 3.456 | 8.020/8.975 | 1.950 | 4.042 |
| 200 | 22/12 | 120 | 106.272 | 12.000 | 4.831 | 12.013/12.966 | 1.931 | 7.380 |
| 200 | 22/22.05 | 80 | 80.000 | 4.173 | 3.636 | 4.174/4.294 | 0.241 | 1.849 |
| 200 | 22/22.05 | 120 | 120.000 | 6.379 | 5.455 | 6.380/6.564 | 0.371 | 3.044 |
| 200 | 26/12 | 80 | 76.032 | 8.000 | 2.924 | 8.026/9.113 | 2.227 | 4.291 |
| 200 | 26/12 | 120 | 106.272 | 12.000 | 4.087 | 12.016/13.086 | 2.172 | 7.746 |
| 200 | 26/22.05 | 80 | 80.000 | 4.173 | 3.077 | 4.192/4.857 | 1.368 | 1.976 |
| 200 | 26/22.05 | 120 | 120.000 | 6.379 | 4.615 | 6.393/7.107 | 1.455 | 3.227 |

## 40W charge-input corner calculation

| Bus / rest cap V | Actual input W | Bus A | Signed cap A | Stored W | ESR W | Converter W |
|---|---|---|---|---|---|---|
| 22/12 | 40.000 | 1.818 | -2.876 | 34.511 | 1.489 | 4.000 |
| 22/22.05 | 0.000 | 0.000 | 0.000 | 0.000 | 0.000 | 0.000 |
| 26/12 | 40.000 | 1.538 | -2.876 | 34.511 | 1.489 | 4.000 |
| 26/22.05 | 0.000 | 0.000 | 0.000 | 0.000 | 0.000 | 0.000 |

At22.05V rest ceiling this model stops charge; cell limits can stop earlier. Power conservation checked in W, signed capacitor charging current is negative.

## Sanity checks and proposed setting arithmetic

- Local-link precharge100R/6x470uF/26V: I0=0.260A, P0=6.760W, resistor energy=0.95316J, t95=0.84480s. Loads ignored.
- Dump100R, +30%C: initial=4.862W, energy to1V=1752.120J, ideal time=2234.1s.1V is only proposed inspection/service investigation target.
- Permanent10k bleed +30%C: initial=0.04862W, time to1V=62.06h; OFF is not safe.
- Available nominal ideal useful energy950.5625J; +30%C1235.73125J. Stored total at22.05V1350.5625J nominal. External dump thermally rated separately.
- 12A cell-bank ESR loss=25.92W initially; 2x aging51.84W.1s/30s pulse-only mean=0.864/1.728W, excludes normal current and all other losses.
- WSK2512 1W70C rating is board/ambient dependent.3mR at12A=0.432W; modeled IL RMS≈12.02A gives≈0.433W. Pulse/derating are not yet accepted.
- IL comparator nominal threshold3.288*10k/(35.7k+10k) -> 11.9912A with gain20/3mR. Not coordinated maximum fault current.
- Port INA293A1/TLV3202 thresholds: BUS3.3*10/68.7/0.06=8.006A; CAP3.288*10/45.7/0.06=11.991A. See rev_a_limits_results.md for±7% provisional allowance and0.5us required clearing; INA301 rejected for40V absmax versus45.4V TVS clamp.
- Independent TLV4311.24V reference: bus OV221k/10k ->28.644V; bus UV154k/10k ->20.336V; bank OV172k/10k ->22.568V nominal. These are hardware backup proposals, distinct from operating window.
- Loaded voltage dividers including100k ADC drain: bus36V->2.46555V; cap24.3V->2.13798V. Clamp2.7V plus diode drop/mux3.6V need transient test.2uA off-leakage *100k=0.2V proposed bound.
- Current midscale1.65V: BUSgain50 +-8A->0.45..2.85V; CAP/ILgain20 +-20A->0.45..2.85V; ideal12-bit steps5.37/13.43mA. Actual clamp/swing can reduce range.
- Approximate beta NTC trip including100k ADC load: FET/L->69.47C; BANK->53.67C. Mux OFF removes this load, so threshold is state-dependent; manufacturer R/T calibration and partial-power tests mandatory.
- Fast IL shutdown estimate must include INA293 dynamic response, comparator, logic, latch/AND, driver/gate and Lmin. No guaranteed max latency is inferred from bandwidth or typical delays.
- For a fault: excursion roughly Vfault/Lmin*tclear. At26V/14.08uH, 1us adds1.847A. This is NOT an accepted1us clearing time, and saturation worsens it.
- Qg53nC / bootstrap effective200nF =0.265V charge droop before leakage/bias.470nF nominal needs DC-bias capacitance, duty/refresh and UVLO verification.
- Aux Type3 ripple:12V300kHz, RA1M/CA1nF gives~20mV at24V;3.3V~301kHz, RA475k/CA1nF gives~20mV. CA exceeds10/(fs*RFB_parallel); CB100pF permits provisional settling >=270/52.5us. Datasheet equations only; stability not simulated.
- Peak duration and repetition are adjustable assumptions; existing runtime calculations are not permission for those pulses.

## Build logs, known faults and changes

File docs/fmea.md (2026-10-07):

# Routing-stage risk update — 2026-10-07

PCB CAD routing is complete;native missing0,DRC0/0,parity0,ERC0/0. See [current routing review](pcb_routing_completion.md). Protective schematic topology/netlist remain unchanged. These additions do not replace the unmeasured protection/thermal/isolation risks below.

| Failure mode | Cause | Effect | Detection | Protection | Residual risk |
|---|---|---|---|---|---|
| Local reference return detour / switching pickup |Bounded MCU In1 signal escapes create local ground slots |ADC bias/noise,spurious supervision/fault or degraded communications |Low-energy scope/ADC/noise tests;inspect return path against actual stackup |GND plane remains one filled polygon;all GND pads connected;hardware default-OFF paths retained |CAD continuity does not qualify signal integrity or OC timing |
| Auxiliary supply neck heating / voltage drop |0.20 mm local escapes,shared actuator current,unknown copper/plating |Supply dip,reset,contact dropout,localized heat |Rail voltage/current and temperature tests at approved coil load |Widened clear trunks0.30–0.70 mm,UVLO/window and independent kill remain |Current sharing/ampacity and repeated actuation not measured |

## Historical FMEA records (preserved)

# Routing checkpoint — 2026-10-04

**Routing incomplete.** 保存したPCBは電力7ネットの全パッド接続と、局所GND/一部信号配線を追加したcheckpoint。native未接続 **610本**（239 nets）、寸法・間隔DRC **0 errors/0 warnings**、schematic parity0。元の935本から325本を解消したが、配線完成/製造/通電/性能保証は意味しない。

現在の結果と残りを[配線作業記録](pcb_routing_completion.md)で確認する。以下は以前の経緯を含む。

## Current PCB residual risks

| Failure mode | Cause | Effect | Detection | Protection | Residual risk |
|---|---|---|---|---|---|
| Unconnected kill/permit/measurement paths |610 remaining links on239 nets |Intended protection and control behavior cannot be relied on |Native ratsnest and ranked remaining-routes report |Schematic protections retained;PCB connections still incomplete |No assembled functional board or energizing release |
| Incomplete ground/return network |11 missing GND links and retained provisional In1 signals |Floating reference or disrupted signal return |Physical pad-cluster report;layer inspection |Local ground fanout added and checked;plane-preserving candidate not adopted |Kelvin/ADC/fault behavior not established |
| Power path thermal/EMI fault |Unmeasured actual copper/plating,loops and cooling |Overheating or switching/fault interference |Width/layer audit now;physical validation remains unperformed |Explicit trunks and parallel vias;hardware protections retained in schematic |Electrical continuity andDRC0 do not establish current capacity or fault containment |

## Historical records before this routing checkpoint

# Clearance approval update — 2026-10-04

39対象ICの内部fine-pitchパッド間0.15 mmをユーザー承認に基づき許容し、その他の銅箔間隔は0.20 mm以上を維持した。DRCの寸法・間隔違反0/0、未接続935本。[検証記録](pcb_rev_a_validation.md)を現状として優先する。以下は変更前の経緯を含む。

# PCB engineering authorized — 2026-10-04

ユーザーがsurge・OC遮断時間・fuse/接触器協調・熱・放電時間の実測前にPCB配置/配線へ進むことを明示承認した。[現行PCB記録](pcb_rev_a.md)を優先する。未実測の項目はPrototype Assumptionとして保持し、製造/通電/性能保証にはしない。以下の「PCB未承認/開始しない」は過去時点の記録として残す。

## PCB-specific residual risks — 2026-10-04

| Failure mode | Cause | Effect | Detection | Protection | Residual risk |
|---|---|---|---|---|---|
| Power copper overheating |Provisional necks/inner SW routing/via concentration |Loss,open circuit or damaged laminate |Layer/width audit,IR and temperature testing later |Current clamp and thermal shutdown retained |Partial routes are not accepted for current capacity;manual power routing required |
| Sensing/kill noise coupling |Kelvin paths on reference layer,return cuts,large switching loops |Incorrect current estimate,spurious fault or delayed kill |Close-up route review;later low-energy waveform tests |Independent fault latch/default-OFF logic retained |935 native unconnected edges prevent functional PCB claims |
| Harness misconnection |Unkeyed solder wire lands and external assemblies |Reverse polarity,tap fault or protection bypass |Named-net assembly map,independent continuity/polarity inspection |External tap resistors,fuses and manual disconnect retained |No assembled harness or fabrication release;fixture strain relief required |
| Fine-pitch fabrication defect |0.15 mm library gaps versus0.20 mm project hard minimum |Copper bridge or unreliable assembly |218 retained DRC clearance errors;fabricator/package review |No DRC exclusions or minimum reduction applied |Explicit process/rule decision unresolved |

## Historical records (preserved)

# Prototype Rev A — 2026-10-04 delegated decisions

ユーザーの委任に基づき、セル監視RAM設定・exact passive選定・外部ベンチ遮断アセンブリ・保護/熱/放電検証基準を[現行選定書](rev_a_design_freeze.md)へ確定した。選定はPrototype Assumption、実測検証は未実施。平均cap電流の初期上限9.5 A、OC約12 A、目標遮断0.5 µs、各link bulk6×470 µF、precharge timeout3 s。12 A/120 Wは後続の検証目標として保持。PCB placement/通電は開始しない。以下の2026-10-03以前の未選定表示は経緯記録であり、この選定書が優先する。

# Prototype Rev A — current status

2026-10-03 JST。**Current: Prototype Rev A schematic only.** Task2 architectureはユーザー採用承認済み。実機条件未確認は[Prototype envelope](../docs/prototype_rev_a_envelope.md)に明示した **ASSUMPTION — MUST VERIFY ON PROTOTYPE** として隔離し、詳細electrical schematicを作成した。部品/保護閾値はprototype候補で性能保証ではない。[現行review](../docs/rev_a_schematic_review.md)と[pinout](../docs/pinout.md)が現在の設計記録。PCB placement/routing、firmware、通電、120W使用許可、競技適合、Task4開始は未承認。以下の旧status/approval pending/skeleton-only記述はhistorical recordであり現在statusではない。

## Rev A FMEA additions (current architecture)

| Failure mode | Cause | Effect | Detection | Protection | Residual risk |
|---|---|---|---|---|---|
| Cell OV / imbalance |leakage/mismatch/config wrong|cell damage|BQ per-cell/ADC bank|autonomous configured DCHG/DDSG + latch|RAM profile selected but not programmed/read back;slow trim |
| Cell open-wire |tap break/short|false cell reading/short energy|BQ open-wire + plausibility|charge inhibit/tap series|source/onboard1k tap resistors selected;harness shorts/open-wire settling must be tested |
| Overcurrent / L saturation |short/load/control error|rapid heating/current rise|INA293 pairs/TLV3202|latch/PWM AND/EN/FLT1|trip~12A with±7% planning allowance;required0.5us clearing/saturation unverified |
| MOSFET short |surge/heat/shoot-through|diode/short reverse path|port/current/rail faults|external disconnect/fuse candidates|DC breaking coordination not approved |
| MOSFET open |bond/gate failure|diode stress/loss of control|command-current mismatch|latched inhibit|firmware absent, residual IL energy |
| Driver failure |bias/glitch/stuck output|uncommanded FET|rail window/OC|EN+input kill+external isolation|stuck output ignores logic; actual ringing |
| Sensor failure |shared shunt/reference/open input|false safe current/temp|independent fast front end + plausibility|hardware windows/latch|shared-element failures, firmware absent |
| MCU crash / CAN loss |software/link failure|stale assist request|external watchdog/lease|default-off reset/latch|unconditional heartbeat defeats watchdog; lease unimplemented |
| Thermal fault |bank ESR/core/poor cooling|cell/FET/L overheating|three NTC + hardware windows|disable/contact release|probe lag, thresholds assumed, enclosure unknown |
| Precharge failure |welded bypass/open resistor|inrush/failed start|raw/link ΔV + feedback/timeout|NO paths/upstream isolate|firmware interlock/pulse test absent |
| Discharge failure |aux loss/open dump/short Q|energy remains or prolonged heat|meter/time/NTC/LED|permanent bleed + service tool|LED dark misleading,62h bleed, tool/rebound unverified |
| Auxiliary failure |UV/OV/sequencing|logic/gate unsafe/dump unavailable|PG/supervisor/driver window|latch clear and default-off coils|external actuator rail unresolved, partial-power injection |

Fault taxonomy proposal: WARNING (approach thermal/energy boundary), RECOVERABLE (startup/precharge refused with sources safe), LATCHED (OC/OV/UV/temp/CAN lease), CRITICAL (suspected FET/contact short, failed discharge/monitor provisioning). Clear/rearm requires supervised reason; no automatic restart. Categories are architecture requirements, not implemented firmware.

## Historical records (preserved)

# Task 4 prospective PCB risks — no placement yet

次表は配置前のrisk register。Protectionは未実装要求、配置によって実際に発生した不具合ではない。

| Failure mode | Cause | Effect | Detection | Protection | Residual risk |
|---|---|---|---|---|---|
| MOSFET overheating | narrow thermal path/airflow loss | short/fire | hot junction estimate + thermal validation | copper/thermal strategy + derate/trip | boardtemp≠junction |
| inductor overheating | core/Cu loss/hotbias | L低下→OC | winding/core temperature/ripple | Lhot margin/airflow/OC | coreloss未算入 |
| shunt local heating | pulse/RMS/bottleneck | drift/open | Kelvin error/temp | ratedpulse/thermalspread | nearbyamp tempdrift |
| connector heating | contact/cable/retention | arc/melt | temperature/drop/inspection | keying/retention/derating | vibration/aging |
| copper bottleneck | neck/via/pad current crowding | localburn | rule/thermal/currentpath review | area/return/via sharing検証 | RMS/peak不明 |
| misleading NTC position | heat lag/remote sensor | delayedtrip | thermal mapping/fault tests | representative hotspot placement | unmonitored hotspot |
| sensing noise | SW/L/return coupling | control/fault誤動作 | synchronized sample/noise test | Kelvin/analog zone/reference continuity | common reference fault |
| gate ringing | long gate/return loop | falseON/shootthrough | differentialVGS measurement | drivernearFET/localreturn/deadtime | parasitic transient未検証 |

---

# Task 3 candidate review FMEA additions

Protection列は未実装要求。各故障はTask 2表と併せて扱い、回路ERCや保護検証の完了を意味しない。

| Failure mode | Cause | Effect | Detection | Protection | Residual risk |
|---|---|---|---|---|---|
| slow OC clearing | EN-only kill/amp settling/blanking | I上昇、15 A port超過/半導体stress | measured end-to-end delay/current | independent comparator→latch→input clamp+timer fault、EN backup | maxdelay/source impedance/Ttrip未確定 |
| shunt open / short | solder/crack/bridge | power interruption/amp overstress or hidden current | redundant port/IL consistency、diagnostic range | no rearm、independent source interruption | 共用shuntのsingle-point blind fault |
| sense amplifier stuck / rail | aux/reference/CM transient | false current limit | range/command consistency/reference check | separate fast front-end要求 | amp共用ならOCも失敗 |
| divider open / short | resistor/ADC clamp damage | false lowV/ADC overvoltage | independent OV/cell sum/range | charge inhibit/ADC injection protection | divider/OV共通reference |
| precharge bypass stuck ON | FETshort/contact weld | insertion inrush | isolation/ΔV/current feedback | separate disconnect、arm interlock | unexpected bank/bodydiode backfeed |
| dump switch stuck ON / OFF | gate/solder/short | resistor overheat / stored energy | V decay/temperature/current | thermal cutoff、independent meter/service path | auxOFF/indicatorOFFでもenergy残留 |
| aux regulator fail | surge/short/startup | unsafe driver or MCU state | rail supervisor/UVLO | default OFF、independent kill、reverse blocking | common supply lossで保護も停止 |
| L saturation | tolerance/bias/hot | ripple/di-dt増大 | external fast OC + validated L curve | threshold/latency/Isat coordination | typ25°C Isatでは保証不能 |

---

# Task 2 FMEA update

qualitative、未実装、RPN/Ttrip/clear energyはTBD。Protectionは要求。各faultはfault latch→killと必要な両側disconnectを使う。normal recoverableでもautomatic rearm禁止。

| Failure mode | Cause | Effect | Detection | Protection | Residual risk |
|---|---|---|---|---|---|
| capacitor overvoltage [LATCHED] | control/regen/divider fault | cell vent | bank independent OV + cell monitor | charge inhibit / isolate | threshold/latency、dump thermal |
| cell imbalance [WARNING→LATCHED] | C/leak/temp/shunt fault | cell OV/UV/reversal | per-cell min/max/open-wire | switched passive balance、OV kill/UV stop | tap/monitor common failure |
| overcurrent [LATCHED→CRITICAL] | short/control/lowV | energy into PCB/FET | external fast comparator + port sensing | latch/kill、DC disconnect/fuse coordination | clearing前stress、same shunt fault |
| MOSFET short [CRITICAL] | thermal/avalanche/shootthrough | bus-bank uncontrolled conduction | current/ΔV abnormal、isolation feedback | both-source independent interrupt | failed disconnect/body diode/internal bank short |
| MOSFET open [LATCHED] | bond/driver/solder | diode overload/no transfer | command-current mismatch | kill/log/inspect | local hotspot before detection |
| gate driver failure [LATCHED→CRITICAL] | UVLO/stuck output | shootthrough/unwanted gate | rail/fault/current | EN default OFF + independent disconnect | stuck-high not solved by PWM OFF |
| inductor saturation [CRITICAL] | overload/hot/dc bias | rapidly rising current | fast OC / current slope | kill and latch、Isat/Ttrip coordination | delay di/dt、core damage |
| sensor failure [LATCHED] | amp/reference/tap/open/stuck | false safe feedback | rails/range/cell sum/reference/open-wire | no arm、external protection | common reference/shunt/supply failure |
| MCU crash [LATCHED] | clock/hardfault/debug/watchdog | retained PWM | external heartbeat supervisor | hardware kill + timer fault | reaction time/clock shared causes |
| CAN loss [RECOVERABLE] | cable/busoff/stale | stale power request | counter/timeout/busoff | inhibit + explicit rearm | timeout energy、official module offline |
| thermal fault [WARNING→LATCHED/CRITICAL] | ESR/airflow/contact/core | degradation/fire | 3 representative NTC + validation thermography | derate/trip、no hot dump | unmonitored hotspot/lag |
| precharge failure [LATCHED] | resistor open/bypass welded | inrush/no startup | ΔV/I/time/feedback | bypass interlock/isolation | contact feedback ambiguous |
| discharge-path failure [LATCHED] | bleed open/dump fail/aux loss | residual bank energy | independent meter/rebound/indicator selfcheck | lockout + service discharge | service error/indicator failure |
| input loss [RECOVERABLE→LATCHED] | ref cutoff/battery disconnect | cap backfeed/reboot | bus UV/ref enable/supervisor | assist inhibit / source isolation | diode conduction、aux collapse |
| disconnect failure [CRITICAL] | welded/short switch | continuing fault current | feedback/current after kill | alternate interrupt/fuse | DC arc、fault coordinationTBD |

Fault thresholds、latency、primary/secondary sensor独立性、pulse熱、single bank port合規、Safe判定は未解決。詳細回路へ進む前にレビューする。

---

## Task 1 record (historical; Task 2 above takes precedence)

# Preliminary FMEA

2026-10-03。定性分析のみ。Protectionは要求/候補で、実装済みではない。
Severity/occurrence/detectionの数値RPNは故障率・試験根拠がなく未採点(TBD)。閾値・反応時間・遮断能力もTBD。

| Failure mode | Cause | Effect | Detection | Protection | Residual risk |
|---|---|---|---|---|---|
| control MCU failure | crash、clock、brownout、stuck PWM、debug halt | uncontrolled current / charge | external watchdog、fault inputs、heartbeat | default OFF、independent hardware trip/latch | watchdog前のenergy、shared supply |
| gate driver failure | UVLO、supply OV、stuck output | gate loss、shoot-through、unwanted conduction | rail/fault monitoring、current trip | enable bias OFF、UVLO、isolation candidate | stuck-high / FET短絡はPWMで停止不可 |
| MOSFET short | overvoltage、thermal、shoot-through | bus↔bank直結またはground短絡 | fast current / voltage異常 | source/bank側energy isolationとfuse候補 | fault clearing energy、DC arc、diode path |
| MOSFET open | bond failure、solder、driver断線 | transfer喪失、他素子過負荷 | current command対feedback不一致 | stop・fault latch | diode熱、局所hotspot |
| current sensor failure | shunt/amp/reference断線、飽和、stuck | incorrect feedback、overcurrent | range/rate/plausibility、independent comparator | inhibit、separate fast trip candidate | shared shunt/reference common failure |
| voltage sensor failure | divider open/short、ADC、reference mismatch | 偽低電圧で過充電 | cell sum/bank相関、range、reference診断 | independent OV、charge inhibit | plausible stuck-low |
| capacitor imbalance | C/leakage/temperature差、balance failure | cell OV/UV/reversal | per-cell min/max/delta | charge inhibit、balance、UV assist stop | monitor tap共通故障、balancer不足 |
| bank overvoltage | loop error、regeneration、sense誤差 | cell損傷・vent | bank/cell sense、independent threshold | charge stop、isolation/energy sink候補 | sink許容power不明、transient overshoot |
| overcurrent | short、bad command、low Vcap、control instability | FET/L/PCB熱、connector arc | fast current、cycle trip候補 | independent inhibit、fuse/isolation | trip前stress、fuse coordination |
| overtemperature | airflow loss、ESR、connector resistance | aging、short/open、火災 | selected hotspot sensors、derating trend | derate→trip、sensor fault診断 | thermal lag、unmonitored hotspot |
| CAN loss | bus-off、disconnect、stale frames | uncontrolled/stale assist budget | timestamp/counter/timeout | inhibit、latched safe mode、explicit rearm | timeout内energy、robot integration影響 |
| input power loss | battery disconnect、brownout | aux loss、cap backfeed、reboot | bus UV、reset cause | gate OFF、reverse flow対策、service discharge | cap側auxが意図せず継続、bleed不能 |
| shorted bank wiring | abrasion、tool、tap short | large discharge、arc | current trip、inspection | bank-sidefault interruption、tap current制限、enclosure | bank内部短絡は外部fuseで止まらない |
| reverse polarity | miswire / connector error | reverse cell stress、FET diode conduction | polarity sensing、mechanical key | blocking候補、禁止connection | failed blocking device |
| precharge failure | bypass welded/open、resistor open、wrong sequence | inrush / no startup | ΔV/current/time、main feedback | timeout latch、bypass inhibit | contact状態の診断限界 |
| bleed/discharge failure | resistor open、switch stuck OFF、aux loss | OFF後energy残留 | independent voltage measurement、rebound check | alternate service discharge、lockout | tool/測定ミス、cell残留 |
| discharge stuck ON | switch short、firmware fault | unnecessary熱 / cell UV | voltage fall/current/temp | limit thermal energy、cell UV監視 | aux不要のpassive pathは遮断困難 |
| temperature sensor failure | NTC断線/短絡、ADC故障 | 偽低温で運転継続 | open/short/range診断 | fault inhibit / conservative derating | 同一ADC common failure |
| reverse current | FPWM、body diode、source collapse | robot/batteryへの逆給電 | signed current / bus state | zero-current guard、blocking/isolation候補 | PWM OFFでdiode conduction |
| connector opens under load | vibration、manual removal | arc、bus transient、contact heating | continuity/voltage異常、inspection | strain relief、load OFF手順、arc防護 | sudden mechanical failure |
| PCB overheating | via不足、bad solder、return loop、aging | delamination / short / fire | thermal test、current and hotspot | thermal/current derating、layout review | 隠れたcontact hotspot |

最大riskはstored energyの短絡供給、single cell過電圧、shorted switchの遮断不能、sensor共通故障、shutdown後残留。
各riskは検出不能ケースを含めTask 2 gateでレビューし、未解決を消さない。

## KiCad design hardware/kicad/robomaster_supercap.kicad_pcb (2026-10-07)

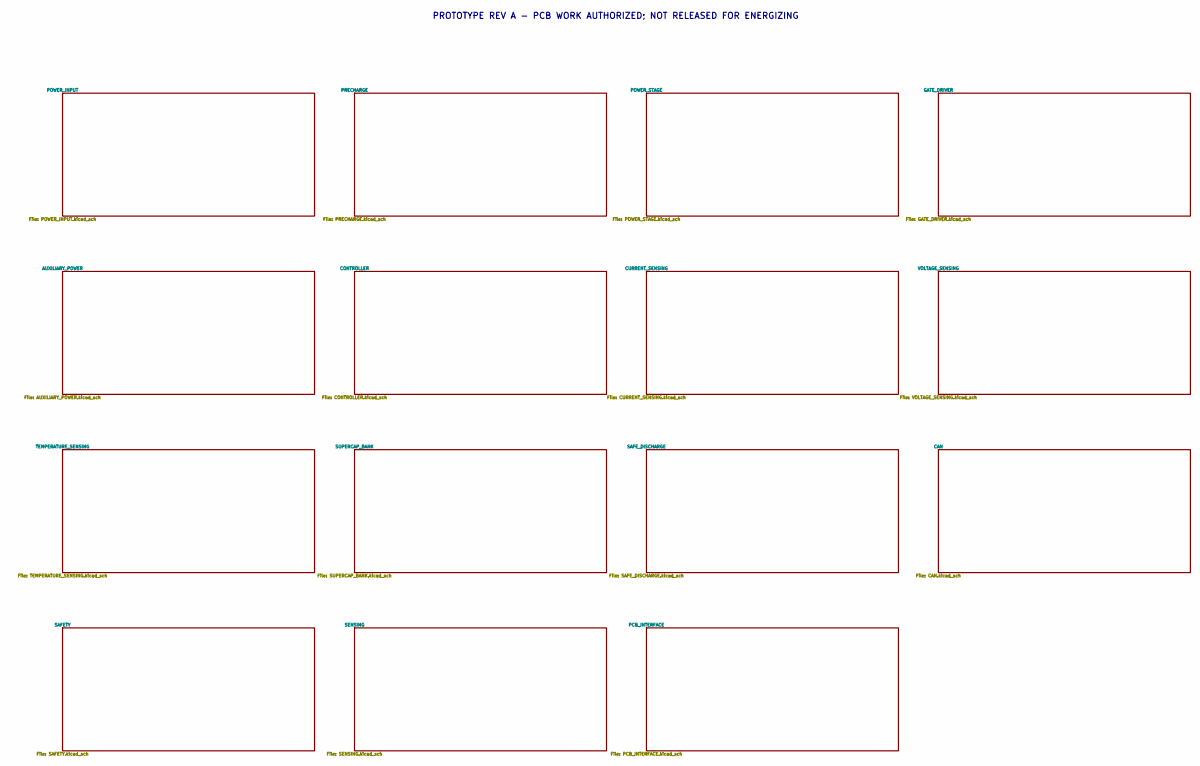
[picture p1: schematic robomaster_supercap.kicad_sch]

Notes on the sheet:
PROTOTYPE REV A - PCB WORK AUTHORIZED; NOT RELEASED FOR ENERGIZING

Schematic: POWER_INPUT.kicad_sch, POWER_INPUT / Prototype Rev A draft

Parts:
D1: SMBJ28A / no surge-energy guarantee; D_SMB; MPN SMBJ28A
D2: SMBJ18CA bidirectional coil suppression / release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; D_SMB; MPN SMBJ18CA
F1: 0997010.WXN / MINI997 58V10A / external 0FHM0002Z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; MPN 0997010.WXN
F2: 0997005.WXN / MINI997 58V5A / external 0FHM0002ZX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; MPN 0997005.WXN
J1: ROBOT BUS / external covered bolted power termina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
J2: BUS_ISO actuator+reserved diagnostic / no intrins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
J3: referee permit interface / no bypass
K1: BUS_ISO external NO contact / AEV14012 bench sele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; MPN AEV14012
Q1: CSD18540Q5B; VSONP-8-1EP_5x6_P1.27mm; MPN CSD18540Q5B
Q2: BC857B; SOT-23; MPN BC857B,215
Q3: BC847B; SOT-23; MPN BC847B,215
R1, R2, R3, R7, R8: 10k; R_0805_2012Metric; MPN CRCW080510K0FKEA
R4: 4.7k; R_0805_2012Metric; MPN CRCW08054K70FKEA
R5: 100k; R_0805_2012Metric; MPN CRCW0805100KFKEA
R6: 47R; R_0805_2012Metric; MPN CRCW080547R0FKEA
U1: Blue Sea6006 / external manual source disconnect;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; MPN 6006
U2: DDR-60L-12 / external bench actuator supply; MPN DDR-60L-12

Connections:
ACTUATOR_12V: D2.1 (K), J2.1, K1.3 (COIL_P), Q2.2 (E), R2.2 (B), U2.3 (VO_P), U2.4 (VO_P); also elsewhere on the board
BUS_FUSED: D1.1 (K), F1.2 (B), K1.1 (COM); also elsewhere on the board
BUS_ISO_COIL_GATE: Q1.2 (G_DS4), R1.1 (A), R6.2 (B)
BUS_ISO_COIL_M: D2.2 (A), J2.2, K1.4 (COIL_M), Q1.3 (D_DS5_6_7_8); also elsewhere on the board
BUS_ISO_DRIVE: R4.1 (A); also elsewhere on the board
BUS_ISO_FB: J2.3, R7.1 (A); also elsewhere on the board
BUS_ISO_NPN_C: Q3.3 (C), R3.2 (B)
BUS_ISO_NPN_C_BASE: Q3.1 (B), R4.2 (B), R5.1 (A)
BUS_ISO_PNP_B: Q2.1 (B), R2.1 (A), R3.1 (A)
BUS_ISO_PNP_C: Q2.3 (C), R6.1 (A)
GND: D1.2 (A), J1.2, J2.4, J3.2, Q1.1 (S_DS1_2_3), Q3.2 (E), R1.2 (B), R5.2 (B), R7.2 (B), R8.2 (B), U2.1 (VO_M), U2.2 (VO_M), U2.6 (VIN_M); also elsewhere on the board
unnamed: F1.1 (A), F2.1 (A), J3.1, U1.2 (SWITCHED)
unnamed: F2.2 (B), U2.5 (VIN_P)
unnamed: J1.1, U1.1 (COM)
REFEREE_PERMIT: J3.3, R8.1 (A); also elsewhere on the board

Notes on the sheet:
Aux input is BUS_FUSED upstream of NO isolate. No bank-fed control rail.
Four AEV14012 main/bypass contacts, 12V coils; external DDR-60L-12. Bench only: total contact mass about1.6kg.
Fuse+TVS values provisional. TVS cathode positive; reverse insertion is not authorized.

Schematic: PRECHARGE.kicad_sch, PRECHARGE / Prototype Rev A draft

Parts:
D3, D4: SMBJ18CA bidirectional coil suppression / release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; D_SMB; MPN SMBJ18CA
J4: BYP_BUS actuator+reserved diagnostic / no intrins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
J5: BYP_CAP actuator+reserved diagnostic / no intrins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
K2: BYP_BUS external NO contact / AEV14012 bench sele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; MPN AEV14012
K3: BYP_CAP external NO contact / AEV14012 bench sele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; MPN AEV14012
Q4, Q7, Q8, Q11: BC847B; SOT-23; MPN BC847B,215
Q5, Q9: CSD18540Q5B; VSONP-8-1EP_5x6_P1.27mm; MPN CSD18540Q5B
Q6, Q10: BC857B; SOT-23; MPN BC857B,215
R9, R21: 150R; R_0805_2012Metric; MPN CRCW0805150RFKEA
R10, R22: 1.5k; R_0805_2012Metric; MPN CRCW08051K50FKEA
R11, R12, R14, R15, R16, R20, R23, R24, R26, R27, R28, R32: 10k; R_0805_2012Metric; MPN CRCW080510K0FKEA
R13, R25: 100R / HS25 100R F / external chassis mount; MPN HS25 100R F
R17, R29: 4.7k; R_0805_2012Metric; MPN CRCW08054K70FKEA
R18, R30: 100k; R_0805_2012Metric; MPN CRCW0805100KFKEA
R19, R31: 47R; R_0805_2012Metric; MPN CRCW080547R0FKEA
U3, U4: AQZ202G / external precharge SSR; MPN AQZ202G

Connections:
ACTUATOR_12V: D3.1 (K), D4.1 (K), J4.1, J5.1, K2.3 (COIL_P), K3.3 (COIL_P), Q6.2 (E), Q10.2 (E), R15.2 (B), R27.2 (B); also elsewhere on the board
BYP_BUS_COIL_GATE: Q5.2 (G_DS4), R14.1 (A), R19.2 (B)
BYP_BUS_COIL_M: D3.2 (A), J4.2, K2.4 (COIL_M), Q5.3 (D_DS5_6_7_8); also elsewhere on the board
BYP_BUS_DRIVE: R17.1 (A); also elsewhere on the board
BYP_BUS_FB: J4.3, R20.1 (A); also elsewhere on the board
BYP_BUS_NPN_C: Q7.3 (C), R16.2 (B)
BYP_BUS_NPN_C_BASE: Q7.1 (B), R17.2 (B), R18.1 (A)
BYP_BUS_PNP_B: Q6.1 (B), R15.1 (A), R16.1 (A)
BYP_BUS_PNP_C: Q6.3 (C), R19.1 (A)
BYP_CAP_COIL_GATE: Q9.2 (G_DS4), R26.1 (A), R31.2 (B)
BYP_CAP_COIL_M: D4.2 (A), J5.2, K3.4 (COIL_M), Q9.3 (D_DS5_6_7_8); also elsewhere on the board
BYP_CAP_DRIVE: R29.1 (A); also elsewhere on the board
BYP_CAP_FB: J5.3, R32.1 (A); also elsewhere on the board
BYP_CAP_NPN_C: Q11.3 (C), R28.2 (B)
BYP_CAP_NPN_C_BASE: Q11.1 (B), R29.2 (B), R30.1 (A)
BYP_CAP_PNP_B: Q10.1 (B), R27.1 (A), R28.1 (A)
BYP_CAP_PNP_C: Q10.3 (C), R31.1 (A)
GND: J4.4, J5.4, Q4.2 (E), Q5.1 (S_DS1_2_3), Q7.2 (E), Q8.2 (E), Q9.1 (S_DS1_2_3), Q11.2 (E), R11.2 (B), R12.2 (B), R14.2 (B), R18.2 (B), R20.2 (B), R23.2 (B), R24.2 (B), R26.2 (B), R30.2 (B), R32.2 (B); also elsewhere on the board
unnamed: K2.1 (COM), U3.3 (ACDC_A)
unnamed: K2.2 (NO), R13.2 (B)
unnamed: K3.1 (COM), U4.3 (ACDC_A)
unnamed: K3.2 (NO), R25.2 (B)
unnamed: R13.1 (A), U3.4 (ACDC_B)
unnamed: R25.1 (A), U4.4 (ACDC_B)
PRE_BUS_DRIVE: R10.1 (A); also elsewhere on the board
PRE_BUS_FB: R12.1 (A); also elsewhere on the board
PRE_BUS_LED_M: Q4.3 (C), U3.1 (LED_M); also elsewhere on the board
PRE_BUS_LED_P: R9.2 (B), U3.2 (LED_P); also elsewhere on the board
PRE_BUS_SSR_BASE: Q4.1 (B), R10.2 (B), R11.1 (A)
PRE_CAP_DRIVE: R22.1 (A); also elsewhere on the board
PRE_CAP_FB: R24.1 (A); also elsewhere on the board
PRE_CAP_LED_M: Q8.3 (C), U4.1 (LED_M); also elsewhere on the board
PRE_CAP_LED_P: R21.2 (B), U4.2 (LED_P); also elsewhere on the board
PRE_CAP_SSR_BASE: Q8.1 (B), R22.2 (B), R23.1 (A)
V3V3: R9.1 (A), R21.1 (A); also elsewhere on the board

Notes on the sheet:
PRE_BUS SSR has no auxiliary contact: infer conduction using raw/link ADC; FB pin reserved LOW, not confirmation.
PRE_CAP SSR has no auxiliary contact: infer conduction using raw/link ADC; FB pin reserved LOW, not confirmation.
Separate NO isolate plus NO resistor-path and NO bypass contacts; no permanent path around isolation.
Six470uF per link; 26V/100R t95 nominal0.845s, worst target<1.1s. Timeout3s and delta-V<1V.
SSR path acceptance uses link voltage progression and open-path diagnosis; no resistor-only bank charge.

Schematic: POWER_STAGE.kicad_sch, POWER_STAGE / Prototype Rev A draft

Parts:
C1, C2, C3, C4, C5, C6, C9, C10, C11, C12, C13, C14: 470uF /63V EEUFR1J471 / ripple1.995Arms at100kHz; CP_Radial_D12.5mm_P5.00mm; MPN EEUFR1J471
C7, C8, C15, C16: 2.2uF / 100V X7R / effective C MUST VERIFY; C_1210_3225Metric; MPN GRM32ER72A225KA35L
C17, C18: 1nF /100V DNI tunable; C_0805_2012Metric; MPN C0805C102J1GACTU; not fitted
D5, D6, D7, D8: BZT52H-C15 / gate clamp candidate; D_SOD-123F; MPN BZT52H-C15
L1: XAL1510-223MED / 22uH +/-20%; L_Coilcraft_XAL1510-223; MPN XAL1510-223MED
Q12, Q13, Q14, Q15: CSD18540Q5B; VSONP-8-1EP_5x6_P1.27mm; MPN CSD18540Q5B
R33, R34, R35: WSK25123L000FEA / 3mR 1% 1W; R_Shunt_Vishay_WSK2512_6332Metric_T2.21mm; MPN WSK25123L000FEA
R36, R37, R38, R39: 10k GS mandatory; R_0805_2012Metric; MPN CRCW080510K0FKEA
R40, R41: 10R DNI tunable; R_0805_2012Metric; MPN CRCW080510R0FKEA; not fitted

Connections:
BUS_KELVIN_M: R33.3 (K_M); also elsewhere on the board
BUS_KELVIN_P: R33.2 (K_P); also elsewhere on the board
BUS_LINK: C1.1 (A), C2.1 (A), C3.1 (A), C4.1 (A), C5.1 (A), C6.1 (A), C7.1 (A), C8.1 (A), Q12.3 (D_DS5_6_7_8), R33.4 (I_M); also elsewhere on the board
BUS_LINK_IN: R33.1 (I_P); also elsewhere on the board
CAP_KELVIN_M: R34.3 (K_M); also elsewhere on the board
CAP_KELVIN_P: R34.2 (K_P); also elsewhere on the board
CAP_LINK: C9.1 (A), C10.1 (A), C11.1 (A), C12.1 (A), C13.1 (A), C14.1 (A), C15.1 (A), C16.1 (A), Q14.3 (D_DS5_6_7_8), R34.4 (I_M); also elsewhere on the board
CAP_LINK_IN: R34.1 (I_P); also elsewhere on the board
GATE_AH: D5.1 (K), Q12.2 (G_DS4), R36.1 (A); also elsewhere on the board
GATE_AL: D6.1 (K), Q13.2 (G_DS4), R37.1 (A); also elsewhere on the board
GATE_BH: D7.1 (K), Q14.2 (G_DS4), R38.1 (A); also elsewhere on the board
GATE_BL: D8.1 (K), Q15.2 (G_DS4), R39.1 (A); also elsewhere on the board
GND: C1.2 (B), C2.2 (B), C3.2 (B), C4.2 (B), C5.2 (B), C6.2 (B), C7.2 (B), C8.2 (B), C9.2 (B), C10.2 (B), C11.2 (B), C12.2 (B), C13.2 (B), C14.2 (B), C15.2 (B), C16.2 (B), C17.2 (B), C18.2 (B), D6.2 (A), D8.2 (A), Q13.1 (S_DS1_2_3), Q15.1 (S_DS1_2_3), R37.2 (B), R39.2 (B); also elsewhere on the board
IL_KELVIN_M: R35.3 (K_M); also elsewhere on the board
IL_KELVIN_P: R35.2 (K_P); also elsewhere on the board
IL_TO_L: L1.1 (A), R35.4 (I_M)
SW_NODE_A: D5.2 (A), Q12.1 (S_DS1_2_3), Q13.3 (D_DS5_6_7_8), R35.1 (I_P), R36.2 (B), R40.1 (A); also elsewhere on the board
SW_NODE_A_SNUB: C17.1 (A), R40.2 (B)
SW_NODE_B: D7.2 (A), L1.2 (B), Q14.1 (S_DS1_2_3), Q15.3 (D_DS5_6_7_8), R38.2 (B), R41.1 (A); also elsewhere on the board
SW_NODE_B_SNUB: C18.1 (A), R41.2 (B)

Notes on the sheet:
Body diode S -> D: healthy all-OFF positive rails block static DC; inductor decay or a short high-side FET can feed the other rail.
Shunts: power pads1/4, Kelvin pads2/3. WSK3mR terminal T=2.21mm (not the>=5mR T1.19 land).
Primary fs=200kHz; initial average current cap9.5A maximum,8A normal;12A remains later design goal.

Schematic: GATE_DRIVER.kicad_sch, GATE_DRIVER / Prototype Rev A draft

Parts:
C19, C22: 470nF /50V X7R bootstrap / effectiveC>=200nF targ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; C_0805_2012Metric; MPN GRM21BR71H474KA88L
C20, C23: 1uF /25V X7R; C_0805_2012Metric; MPN GRM21BR71H105KA12L
C21, C24, C26, C27: 100nF / 16V X7R; C_0805_2012Metric; MPN C0805C104K5RACTU
C25: 1nF EN filter; C_0805_2012Metric; MPN C0805C102J1GACTU
D9, D10, D11, D12: 1N4148W DNI turnoff bypass; D_SOD-123; MPN 1N4148W; not fitted
R42, R44, R48, R50: 4.7R gate / tunable; R_0603_1608Metric; MPN CRCW06034R70FNEA
R43, R45, R49, R51: 2.2R DNI turnoff option; R_0805_2012Metric; MPN CRCW08052R20FNEA; not fitted
R46, R47, R52, R53, R54: 10k; R_0805_2012Metric; MPN CRCW080510K0FKEA
U5, U6: UCC27282DRCR; VSON-10-1EP_3x3mm_P0.5mm_EP1.65x2.4mm; MPN UCC27282DRCR
U7, U8: SN74LVC2G08DCUR; VSSOP-8_2.3x2mm_P0.5mm; MPN SN74LVC2G08DCUR

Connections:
GATE_AH: D9.2 (A), R42.2 (B); also elsewhere on the board
GATE_AL: D10.2 (A), R44.2 (B); also elsewhere on the board
GATE_BH: D11.2 (A), R48.2 (B); also elsewhere on the board
GATE_BL: D12.2 (A), R50.2 (B); also elsewhere on the board
GATE_PERMIT: C25.1 (A), R54.1 (A), U5.6 (EN), U6.6 (EN), U7.2 (B1), U7.6 (B2), U8.2 (B1), U8.6 (B2); also elsewhere on the board
GND: C20.2 (B), C21.2 (B), C23.2 (B), C24.2 (B), C25.2 (B), C26.2 (B), C27.2 (B), R46.2 (B), R47.2 (B), R52.2 (B), R53.2 (B), R54.2 (B), U5.9 (VSS), U5.11 (EP), U6.9 (VSS), U6.11 (EP), U7.4 (GND), U8.4 (GND); also elsewhere on the board
HB_A: C19.1 (A), U5.3 (HB)
HB_B: C22.1 (A), U6.3 (HB)
HO_A: R42.1 (A), R43.1 (A), U5.4 (HO)
HO_A_FAST: D9.1 (K), R43.2 (B)
HO_B: R48.1 (A), R49.1 (A), U6.4 (HO)
HO_B_FAST: D11.1 (K), R49.2 (B)
LO_A: R44.1 (A), R45.1 (A), U5.10 (LO)
LO_A_FAST: D10.1 (K), R45.2 (B)
LO_B: R50.1 (A), R51.1 (A), U6.10 (LO)
LO_B_FAST: D12.1 (K), R51.2 (B)
PWM_AH: U7.1 (A1); also elsewhere on the board
PWM_AH_SAFE: R46.1 (A), U5.7 (HI), U7.7 (Y1)
PWM_AL: U7.5 (A2); also elsewhere on the board
PWM_AL_SAFE: R47.1 (A), U5.8 (LI), U7.3 (Y2)
PWM_BH: U8.1 (A1); also elsewhere on the board
PWM_BH_SAFE: R52.1 (A), U6.7 (HI), U8.7 (Y1)
PWM_BL: U8.5 (A2); also elsewhere on the board
PWM_BL_SAFE: R53.1 (A), U6.8 (LI), U8.3 (Y2)
SW_NODE_A: C19.2 (B), U5.5 (HS); also elsewhere on the board
SW_NODE_B: C22.2 (B), U6.5 (HS); also elsewhere on the board
V3V3: C26.1 (A), C27.1 (A), U7.8 (VCC), U8.8 (VCC); also elsewhere on the board
V12_DRIVER: C20.1 (A), C21.1 (A), C23.1 (A), C24.1 (A), U5.1 (VDD), U6.1 (VDD); also elsewhere on the board

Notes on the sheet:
DRC package only: EN pin6, exposed pad11 to VSS. Internal bootstrap diode used.
470nF is provisional: Qg53nC / Ceff200nF=0.265V plus bias/leak loss; both legs refresh each cycle.
No 100% high-side duty. Minimum off/refresh time and deadtime require gate-waveform validation.
Independent AND inhibit stops HI/LI; EN secondary (typ1.5us is not a maximum guarantee).

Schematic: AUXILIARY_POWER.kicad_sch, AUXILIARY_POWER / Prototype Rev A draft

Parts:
C28, C34: 2.2nF /50V X7R mandatory; C_0805_2012Metric; MPN C0805C222K5RACTU
C29, C35: 2.2uF /100V X7R; C_1210_3225Metric; MPN GRM32ER72A225KA35L
C30, C31, C36, C37: 22uF /25V X7R; C_1210_3225Metric; MPN C1210C226K3RACTU
C32, C38: 1nF C0G; C_0805_2012Metric; MPN C0805C102J1GACTU
C33, C39: 100pF C0G; C_0805_2012Metric; MPN C0805C101J1GACTU
L2: 68uH / MSS1246T-683MLB; L_Coilcraft_MSS1246T-XXX; MPN MSS1246T-683MLB
L3: 47uH / MSS1246T-473MLB; L_Coilcraft_MSS1246T-XXX; MPN MSS1246T-473MLB
R55: 909k; R_0805_2012Metric; MPN CRCW0805909KFKEA
R56, R57, R63: 100k; R_0805_2012Metric; MPN CRCW0805100KFKEA
R58, R61, R65: 1M; R_0805_2012Metric; MPN CRCW08051M00FKEA
R59, R66: 82.5k; R_0805_2012Metric; MPN CRCW080582K5FKEA
R60, R67: 10k; R_0805_2012Metric; MPN CRCW080510K0FKEA
R62: 174k; R_0805_2012Metric; MPN CRCW0805174KFKEA
R64: 27.4k; R_0805_2012Metric; MPN CRCW080527K4FKEA
R68: 475k; R_0805_2012Metric; MPN CRCW0805475KFKEA
U9, U10: LM5164DDAR; TI_SO-PowerPAD-8; MPN LM5164DDAR

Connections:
AUX_EN_DRV: R58.2 (B), R59.1 (A), U9.3 (EN)
AUX_EN_MCU: R65.2 (B), R66.1 (A), U10.3 (EN)
AUX_FB_DRV: C33.2 (B), R55.2 (B), R56.1 (A), U9.5 (FB)
AUX_FB_MCU: C39.2 (B), R62.2 (B), R63.1 (A), U10.5 (FB)
AUX_RIPPLE_DRV: C32.1 (A), C33.1 (A), R61.2 (B)
AUX_RIPPLE_MCU: C38.1 (A), C39.1 (A), R68.2 (B)
AUX_SW_DRV: C28.2 (B), L2.1 (A), R61.1 (A), U9.8 (SW)
AUX_SW_MCU: C34.2 (B), L3.1 (A), R68.1 (A), U10.8 (SW)
BST_DRV: C28.1 (A), U9.7 (BST)
BST_MCU: C34.1 (A), U10.7 (BST)
BUS_FUSED: C29.1 (A), C35.1 (A), R58.1 (A), R65.1 (A), U9.2 (VIN), U10.2 (VIN); also elsewhere on the board
GND: C29.2 (B), C30.2 (B), C31.2 (B), C35.2 (B), C36.2 (B), C37.2 (B), R56.2 (B), R57.2 (B), R59.2 (B), R63.2 (B), R64.2 (B), R66.2 (B), U9.1 (GND), U9.9 (EP), U10.1 (GND), U10.9 (EP); also elsewhere on the board
PG_DRV: R60.1 (A), U9.6 (PGOOD); also elsewhere on the board
PG_MCU: R67.1 (A), U10.6 (PGOOD); also elsewhere on the board
RON_DRV: R57.1 (A), U9.4 (RON)
RON_MCU: R64.1 (A), U10.4 (RON)
V3V3: C36.1 (A), C37.1 (A), C38.2 (B), L3.2 (B), R60.2 (B), R62.1 (A), R67.2 (B); also elsewhere on the board
V12_DRIVER: C30.1 (A), C31.1 (A), C32.2 (B), L2.2 (B), R55.1 (A); also elsewhere on the board

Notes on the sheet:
12V rail 1A IC capacity is not the available actuator/thermal budget. External contact coils require separate reviewed actuator supply.
3.3V and driver12V independently bus-fed, no bank-fed MCU rail. UVLO approx19.68V-on/18.37V-off.
COT Type3 ripple RA/CA/CB options: stability/startup/backfeed and actual auxiliary load must be verified.
Feedback:1.2*(1+909k/100k)=12.108V;1.2*(1+174k/100k)=3.288V. PGOOD qualified by safety.

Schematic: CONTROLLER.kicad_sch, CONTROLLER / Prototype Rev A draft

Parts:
C40, C41, C42, C43, C46, C48: 100nF / 16V X7R; C_0805_2012Metric; MPN C0805C104K5RACTU
C44: 4.7uF /16V X7R; C_0805_2012Metric; MPN C0805C475K4RACTU
C45, C47: 1uF /16V; C_0805_2012Metric; MPN GRM21BR71H105KA12L
C49: 100nF; C_0805_2012Metric; MPN C0805C104K5RACTU
J6: SWD reference voltage ONLY / do not externally po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; PinHeader_1x06_P2.54mm_Vertical
J7: 3.3V UART / no power pin; PinHeader_1x03_P2.54mm_Vertical
R69: 10R; R_0805_2012Metric; MPN CRCW080510R0FKEA
R70: 0R; R_0805_2012Metric; MPN CRCW08050000Z0EA
R71, R72, R73, R74, R75, R76, R77, R78, R79, R80, R81: 10k; R_0805_2012Metric; MPN CRCW080510K0FKEA
U11: STM32G474RET6; LQFP-64_10x10mm_P0.5mm; MPN STM32G474RET6

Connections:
ARM_PULSE: R77.1 (A), U11.24 (PB0); also elsewhere on the board
BUS_ISO_FB: U11.57 (PB4); also elsewhere on the board
BUS_ISO_REQUEST: U11.38 (PC6); also elsewhere on the board
BUS_I_ADC: U11.18 (PA4); also elsewhere on the board
BUS_RAW_ADC: U11.11 (PC3); also elsewhere on the board
BUS_V_ADC: U11.12 (PA0); also elsewhere on the board
BYP_BUS_FB: U11.59 (PB6); also elsewhere on the board
BYP_BUS_REQUEST: U11.33 (PB11); also elsewhere on the board
BYP_CAP_FB: U11.60 (PB7); also elsewhere on the board
BYP_CAP_REQUEST: U11.41 (PC9); also elsewhere on the board
CAN_RX: R72.1 (A), U11.61 (PB8); also elsewhere on the board
CAN_STANDBY: U11.54 (PC12); also elsewhere on the board
CAN_TX: U11.62 (PB9); also elsewhere on the board
CAP_ISO_FB: U11.58 (PB5); also elsewhere on the board
CAP_ISO_REQUEST: U11.39 (PC7); also elsewhere on the board
CAP_I_ADC: U11.19 (PA5); also elsewhere on the board
CAP_RAW_ADC: U11.22 (PC4); also elsewhere on the board
CAP_V_ADC: U11.13 (PA1); also elsewhere on the board
DUMP_REQUEST: U11.52 (PC10); also elsewhere on the board
GND: C40.2 (B), C41.2 (B), C42.2 (B), C43.2 (B), C44.2 (B), C45.2 (B), C46.2 (B), C47.2 (B), C48.2 (B), C49.2 (B), J6.6, J7.3, R73.2 (B), R74.2 (B), R75.2 (B), R76.2 (B), R77.2 (B), R78.2 (B), R79.2 (B), R80.2 (B), U11.15 (VSS), U11.27 (VSSA), U11.31 (VSS), U11.47 (VSS), U11.63 (VSS); also elsewhere on the board
HW_FAULT_N: U11.46 (PA12); also elsewhere on the board
IL_I_ADC: U11.20 (PA6); also elsewhere on the board
MCU_GATE_REQUEST: R78.1 (A), U11.26 (PB2); also elsewhere on the board
MON_ALERT_HOST: U11.53 (PC11); also elsewhere on the board
MON_CONFIG_VALID: R80.1 (A), U11.55 (PD2); also elsewhere on the board
MON_CS_HOST: R81.1 (A), U11.34 (PB12); also elsewhere on the board
MON_MISO_HOST: U11.36 (PB14); also elsewhere on the board
MON_MOSI_HOST: U11.37 (PB15); also elsewhere on the board
MON_SCLK_HOST: U11.35 (PB13); also elsewhere on the board
NRST: C49.1 (A), J6.5, R71.1 (A), U11.7 (PG10); also elsewhere on the board
PRE_BUS_FB: U11.51 (PA15); also elsewhere on the board
PRE_BUS_REQUEST: U11.30 (PB10); also elsewhere on the board
PRE_CAP_FB: U11.2 (PC13); also elsewhere on the board
PRE_CAP_REQUEST: U11.40 (PC8); also elsewhere on the board
PWM_AH: R73.1 (A), U11.42 (PA8); also elsewhere on the board
PWM_AL: R74.1 (A), U11.43 (PA9); also elsewhere on the board
PWM_BH: R75.1 (A), U11.44 (PA10); also elsewhere on the board
PWM_BL: R76.1 (A), U11.45 (PA11); also elsewhere on the board
REFEREE_PERMIT: U11.23 (PC5); also elsewhere on the board
SWCLK: J6.3, U11.50 (PA14)
SWDIO: J6.2, U11.49 (PA13)
SWO: J6.4, U11.56 (PB3)
TEMP_BANK_ADC: U11.10 (PC2); also elsewhere on the board
TEMP_FET_ADC: U11.8 (PC0); also elsewhere on the board
TEMP_L_ADC: U11.9 (PC1); also elsewhere on the board
UART_RX: J7.2, U11.17 (PA3)
UART_TX: J7.1, U11.14 (PA2)
V3V3: C40.1 (A), C41.1 (A), C42.1 (A), C43.1 (A), C44.1 (A), J6.1, R69.1 (A), R71.2 (B), R72.2 (B), R81.2 (B), U11.1 (VBAT), U11.16 (VDD), U11.32 (VDD), U11.48 (VDD), U11.64 (VDD); also elsewhere on the board
VDDA: C45.1 (A), C46.1 (A), R69.2 (B), R70.1 (A), U11.29 (VDDA)
VREF_ADC: C47.1 (A), C48.1 (A), R70.2 (B), U11.28 (VREF+)
WD_HEARTBEAT: R79.1 (A), U11.25 (PB1); also elsewhere on the board

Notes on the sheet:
PG10 pin7 configured NRST; PB8 pin61 BOOT0 strap/options: boot configuration must be locked to flash before use.
HSI clock for draft, no external crystal. FDCAN bit timing/HSI accuracy must be checked before robot integration.
ADC HRTIM-synchronized sampling; internal comparators are secondary diagnostics, not primary OC shutdown.

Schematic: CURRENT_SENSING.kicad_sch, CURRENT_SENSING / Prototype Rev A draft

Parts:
C50, C52, C53, C54, C56, C57, C58, C60, C61: 100nF / 16V X7R; C_0805_2012Metric; MPN C0805C104K5RACTU
C51, C55, C59: 1nF C0G; C_0805_2012Metric; MPN C0805C102J1GACTU
J8: OC diagnostic outputs / do not load; PinHeader_1x05_P2.54mm_Vertical
R82, R83, R84: 100R; R_0805_2012Metric; MPN CRCW0805100RFKEA
U12: INA240A2D; SOIC-8_3.9x4.9mm_P1.27mm; MPN INA240A2D
U13, U14, U16, U17, U19, U20: INA293A1DBVR; SOT-23-5; MPN INA293A1DBVR
U15, U18: INA240A1D; SOIC-8_3.9x4.9mm_P1.27mm; MPN INA240A1D

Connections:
BUS_FAST_NEG: J8.2, U14.1 (OUT); also elsewhere on the board
BUS_FAST_POS: J8.1, U13.1 (OUT); also elsewhere on the board
BUS_I_FILTER: C51.1 (A), R82.2 (B); also elsewhere on the board
BUS_I_RAW: R82.1 (A), U12.5 (OUT)
BUS_KELVIN_M: U12.1 (INM), U13.4 (INM), U14.3 (INP); also elsewhere on the board
BUS_KELVIN_P: U12.8 (INP), U13.3 (INP), U14.4 (INM); also elsewhere on the board
CAP_FAST_NEG: J8.4, U17.1 (OUT); also elsewhere on the board
CAP_FAST_POS: J8.3, U16.1 (OUT); also elsewhere on the board
CAP_I_FILTER: C55.1 (A), R83.2 (B); also elsewhere on the board
CAP_I_RAW: R83.1 (A), U15.5 (OUT)
CAP_KELVIN_M: U15.1 (INM), U16.4 (INM), U17.3 (INP); also elsewhere on the board
CAP_KELVIN_P: U15.8 (INP), U16.3 (INP), U17.4 (INM); also elsewhere on the board
GND: C50.2 (B), C51.2 (B), C52.2 (B), C53.2 (B), C54.2 (B), C55.2 (B), C56.2 (B), C57.2 (B), C58.2 (B), C59.2 (B), C60.2 (B), C61.2 (B), J8.5, U12.2 (GND), U12.3 (REF2), U13.2 (GND), U14.2 (GND), U15.2 (GND), U15.3 (REF2), U16.2 (GND), U17.2 (GND), U18.2 (GND), U18.3 (REF2), U19.2 (GND), U20.2 (GND); also elsewhere on the board
IL_FAST_NEG: U20.1 (OUT); also elsewhere on the board
IL_FAST_POS: U19.1 (OUT); also elsewhere on the board
IL_I_FILTER: C59.1 (A), R84.2 (B); also elsewhere on the board
IL_I_RAW: R84.1 (A), U18.5 (OUT)
IL_KELVIN_M: U18.1 (INM), U19.4 (INM), U20.3 (INP); also elsewhere on the board
IL_KELVIN_P: U18.8 (INP), U19.3 (INP), U20.4 (INM); also elsewhere on the board
V3V3: C50.1 (A), C52.1 (A), C53.1 (A), C54.1 (A), C56.1 (A), C57.1 (A), C58.1 (A), C60.1 (A), C61.1 (A), U12.6 (VS), U12.7 (REF1), U13.5 (VS), U14.5 (VS), U15.6 (VS), U15.7 (REF1), U16.5 (VS), U17.5 (VS), U18.6 (VS), U18.7 (REF1), U19.5 (VS), U20.5 (VS); also elsewhere on the board

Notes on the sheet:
WSK Kelvin pads2/3 route separately to amplifiers; no power current in sense tracks.
INA240 refs REF1=VS, REF2=GND -> midscale1.65V. +-8A bus and +-20A cap/IL nominal ADC windows.
All fast front ends INA293 CM -4..110V; INA301 rejected because40V absmax is below SMBJ28A45.4V rated clamp.
IL dedicated INA293 opposite polarities, CM -4..110V; PWM edge recovery and latency must be measured.

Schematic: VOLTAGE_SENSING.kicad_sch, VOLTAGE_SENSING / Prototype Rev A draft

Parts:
C62, C63, C64, C65: 4.7nF C0G; C_0805_2012Metric; MPN C0805C472J5GACTU
C66, C67, C68: 100nF / 16V X7R; C_0805_2012Metric; MPN C0805C104K5RACTU
D13, D15, D17, D19: BAT54H signal clamp; D_SOD-123F; MPN BAT54H
D14, D16, D18, D20: BAT54H negative clamp; D_SOD-123F; MPN BAT54H
D21, D22: 1N4148W /100V; D_SOD-123; MPN 1N4148W
R85, R86, R88, R89, R91, R92, R94, R95: 33k /1%; R_0805_2012Metric; MPN CRCW080533K0FKEA
R87, R93: 5.1k /1%; R_0805_2012Metric; MPN CRCW08055K10FKEA
R90, R96: 6.8k /1%; R_0805_2012Metric; MPN CRCW08056K80FKEA
R97: 3.3k /1W; R_2512_6332Metric; MPN CRCW25123K30FKEG
R98: 11.8k /1%; R_0805_2012Metric; MPN CRCW080511K8FKEA
R99: 10k /1%; R_0805_2012Metric; MPN CRCW080510K0FKEA
R100, R101, R102, R103, R104, R105, R106, R107, R108, R109: 100k off leakage drain; R_0805_2012Metric; MPN CRCW0805100KFKEA
U21: TLV431AIDBZR; SOT-23; MPN TLV431AIDBZR
U22, U23, U24: TMUX1511PWR; TSSOP-14_4.4x5mm_P0.65mm; MPN TMUX1511PWR

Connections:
ADC_CLAMP_2V7: D13.1 (K), D15.1 (K), D17.1 (K), D19.1 (K), R97.2 (B), R98.1 (A), U21.2 (K)
BANK_P_RAW: D22.2 (A), R94.1 (A); also elsewhere on the board
BUS_DIV_TOP: R85.2 (B), R86.1 (A)
BUS_FUSED: D21.2 (A), R91.1 (A); also elsewhere on the board
BUS_I_ADC: R104.1 (A), U23.3 (D1); also elsewhere on the board
BUS_I_FILTER: U23.2 (S1); also elsewhere on the board
BUS_LINK: R85.1 (A); also elsewhere on the board
BUS_RAW_ADC: R102.1 (A), U22.8 (D3); also elsewhere on the board
BUS_RAW_DIV_TOP: R91.2 (B), R92.1 (A)
BUS_RAW_V_FILTER: C64.1 (A), D17.2 (A), D18.1 (K), R92.2 (B), R93.1 (A), U22.9 (S3)
BUS_V_ADC: R100.1 (A), U22.3 (D1); also elsewhere on the board
BUS_V_FILTER: C62.1 (A), D13.2 (A), D14.1 (K), R86.2 (B), R87.1 (A), U22.2 (S1)
CAP_DIV_TOP: R88.2 (B), R89.1 (A)
CAP_I_ADC: R105.1 (A), U23.6 (D2); also elsewhere on the board
CAP_I_FILTER: U23.5 (S2); also elsewhere on the board
CAP_LINK: R88.1 (A); also elsewhere on the board
CAP_RAW_ADC: R103.1 (A), U22.11 (D4); also elsewhere on the board
CAP_RAW_DIV_TOP: R94.2 (B), R95.1 (A)
CAP_RAW_V_FILTER: C65.1 (A), D19.2 (A), D20.1 (K), R95.2 (B), R96.1 (A), U22.12 (S4)
CAP_V_ADC: R101.1 (A), U22.6 (D2); also elsewhere on the board
CAP_V_FILTER: C63.1 (A), D15.2 (A), D16.1 (K), R89.2 (B), R90.1 (A), U22.5 (S2)
CLAMP_OR: D21.1 (K), D22.1 (K), R97.1 (A)
CLAMP_REF: R98.2 (B), R99.1 (A), U21.1 (REF)
GND: C62.2 (B), C63.2 (B), C64.2 (B), C65.2 (B), C66.2 (B), C67.2 (B), C68.2 (B), D14.2 (A), D16.2 (A), D18.2 (A), D20.2 (A), R87.2 (B), R90.2 (B), R93.2 (B), R96.2 (B), R99.2 (B), R100.2 (B), R101.2 (B), R102.2 (B), R103.2 (B), R104.2 (B), R105.2 (B), R106.2 (B), R107.2 (B), R108.2 (B), R109.2 (B), U21.3 (A), U22.7 (GND), U23.7 (GND), U24.7 (GND), U24.9 (S3), U24.12 (S4); also elsewhere on the board
IL_I_ADC: R106.1 (A), U23.8 (D3); also elsewhere on the board
IL_I_FILTER: U23.9 (S3); also elsewhere on the board
RAIL_OK: U22.1 (SEL1), U22.4 (SEL2), U22.10 (SEL3), U22.13 (SEL4), U23.1 (SEL1), U23.4 (SEL2), U23.10 (SEL3), U23.13 (SEL4), U24.1 (SEL1), U24.4 (SEL2), U24.10 (SEL3), U24.13 (SEL4); also elsewhere on the board
TEMP_BANK_ADC: R109.1 (A), U24.6 (D2); also elsewhere on the board
TEMP_BANK_FILTER: U24.5 (S2); also elsewhere on the board
TEMP_FET_ADC: R107.1 (A), U23.11 (D4); also elsewhere on the board
TEMP_FET_FILTER: U23.12 (S4); also elsewhere on the board
TEMP_L_ADC: R108.1 (A), U24.3 (D1); also elsewhere on the board
TEMP_L_FILTER: U24.2 (S1); also elsewhere on the board
V3V3: C66.1 (A), C67.1 (A), C68.1 (A), U22.14 (VDD), U23.14 (VDD), U24.14 (VDD); also elsewhere on the board

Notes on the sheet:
TMUX1511 powered-off isolation <=3.6V; independent 2.7V clamp proposal avoids dumping into dead MCU rail.
Divider bus36V ->2.582V; cap24.3V ->2.270V nominal. Clamp forward-V and all partial-power cases MUST VERIFY.
100k ADC-side drain:2uA max powered-off leakage gives0.2V estimate. Include loaded divider/NTC calibration.
Current/NTC outputs are bus-fed; partial-power/backfeed and probe effects remain test gates.

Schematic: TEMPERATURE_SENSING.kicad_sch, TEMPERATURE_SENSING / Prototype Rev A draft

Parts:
C69, C70, C71: 10nF; C_0805_2012Metric; MPN C0805C103J5GACTU
J9: FET NTC probe option; PinHeader_1x02_P2.54mm_Vertical; not fitted
J10: L NTC probe option; PinHeader_1x02_P2.54mm_Vertical; not fitted
J11: BANK NTC probe option; PinHeader_1x02_P2.54mm_Vertical; not fitted
R110, R112, R114: 10k /1%; R_0805_2012Metric; MPN CRCW080510K0FKEA
R111, R113, R115: NTCLE100E3103JB0 /10k NTC B3977; PinHeader_1x02_P2.54mm_Vertical; MPN NTCLE100E3103JB0

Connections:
GND: C69.2 (B), C70.2 (B), C71.2 (B), J9.2, J10.2, J11.2, R111.2 (B), R113.2 (B), R115.2 (B); also elsewhere on the board
TEMP_BANK_FILTER: C71.1 (A), J11.1, R114.2 (B), R115.1 (A); also elsewhere on the board
TEMP_FET_FILTER: C69.1 (A), J9.1, R110.2 (B), R111.1 (A); also elsewhere on the board
TEMP_L_FILTER: C70.1 (A), J10.1, R112.2 (B), R113.1 (A); also elsewhere on the board
V3V3: R110.1 (A), R112.1 (A), R114.1 (A); also elsewhere on the board

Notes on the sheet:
3 representative hotspots; optional connector replaces fitted NTC, not parallel second thermistor.
Open NTC reads high, short reads zero. Firmware faults both extremes; hardware thermal window also in SAFETY.
Trip reference options: bank ~55C, FET/L ~70C investigation only; hotspot-to-junction lag unresolved.

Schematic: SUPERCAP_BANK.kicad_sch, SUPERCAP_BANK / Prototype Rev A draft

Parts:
C72, C73, C74, C75, C76, C77, C78, C79, C80: 50F /2.7V SCCV40B506SRB / external cell; MPN SCCV40B506SRB
C81, C82, C83, C84, C85, C86, C87, C88, C89: 100nF /50V X7R; C_0805_2012Metric; MPN C0805C104K5RACTU
C90, C91, C92, C93, C94: 100nF / 16V X7R; C_0805_2012Metric; MPN C0805C104K5RACTU
C95: 1uF /50V X7R; C_0805_2012Metric; MPN GRM21BR71H105KA12L
C96, C97, C98: 1uF /16V; C_0805_2012Metric; MPN GRM21BR71H105KA12L
D23: SMBJ18CA bidirectional coil suppression / release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; D_SMB; MPN SMBJ18CA
F3: 0997015.WXN / MINI997 58V15A / external 0FHM0002Z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; MPN 0997015.WXN
J12: 9S bank power -> official module external boundary
J13: CAP_ISO actuator+reserved diagnostic / no intrins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
J14: Protected 9S taps / source resistors at electrode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
K4: CAP_ISO external NO contact / AEV14012 bench sele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; MPN AEV14012
Q16: CSD18540Q5B; VSONP-8-1EP_5x6_P1.27mm; MPN CSD18540Q5B
Q17: BC857B; SOT-23; MPN BC857B,215
Q18: BC847B; SOT-23; MPN BC847B,215
Q19: BC847B preregulator / voltage thermal MUST VERIFY; SOT-23; MPN BC847B,215
R116, R117, R118, R122, R143, R144, R145, R146, R147, R150, R151, R155, R156: 10k; R_0805_2012Metric; MPN CRCW080510K0FKEA
R119: 4.7k; R_0805_2012Metric; MPN CRCW08054K70FKEA
R120: 100k; R_0805_2012Metric; MPN CRCW0805100KFKEA
R121: 47R; R_0805_2012Metric; MPN CRCW080547R0FKEA
R123, R124, R125, R126, R127, R128, R129, R130, R131, R132: 1k /1W EXTERNAL cell-terminal tap resistor; MPN CRCW25121K00FKEG
R133, R134, R135, R136, R137, R138, R139, R140, R141, R142: 1k /1W tap protection / no bypass; R_2512_6332Metric; MPN CRCW25121K00FKEG
R148: 100R; R_0805_2012Metric; MPN CRCW0805100RFKEA
R149: 0R; R_0805_2012Metric; MPN CRCW08050000Z0EA
R152, R153, R154: 10k TS commissioning option; R_0805_2012Metric; MPN CRCW080510K0FKEA
U25: Blue Sea6006 / external manual bank disconnect;no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; MPN 6006
U26: BQ7694204PFBR; TQFP-48_7x7mm_P0.5mm; MPN BQ7694204PFBR
U27: SN74LV1T34DBVR; SOT-23-5; MPN SN74LV1T34DBVR
U28: TPS3839K33DBZR; SOT-23; MPN TPS3839K33DBZR
U29: SN74LVC2G08DCUR; VSSOP-8_2.3x2mm_P0.5mm; MPN SN74LVC2G08DCUR
U30, U31: TMUX1511PWR; TSSOP-14_4.4x5mm_P0.65mm; MPN TMUX1511PWR

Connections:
ACTUATOR_12V: D23.1 (K), J13.1, K4.3 (COIL_P), Q17.2 (E), R117.2 (B); also elsewhere on the board
BANK_P_RAW: C80.1 (A), J12.1, R132.1 (A), R148.1 (A), R150.1 (A), R151.1 (A), U25.1 (COM); also elsewhere on the board
CAP_ISO_COIL_GATE: Q16.2 (G_DS4), R116.1 (A), R121.2 (B)
CAP_ISO_COIL_M: D23.2 (A), J13.2, K4.4 (COIL_M), Q16.3 (D_DS5_6_7_8); also elsewhere on the board
CAP_ISO_DRIVE: R119.1 (A); also elsewhere on the board
CAP_ISO_FB: J13.3, R122.1 (A); also elsewhere on the board
CAP_ISO_NPN_C: Q18.3 (C), R118.2 (B)
CAP_ISO_NPN_C_BASE: Q18.1 (B), R119.2 (B), R120.1 (A)
CAP_ISO_PNP_B: Q17.1 (B), R117.1 (A), R118.1 (A)
CAP_ISO_PNP_C: Q17.3 (C), R121.1 (A)
CELL0_FILTER: C81.2 (B), R133.2 (B), U26.16 (VC0)
CELL1_FILTER: C81.1 (A), C82.2 (B), R134.2 (B), U26.15 (VC1)
CELL2_FILTER: C82.1 (A), C83.2 (B), R135.2 (B), U26.14 (VC2)
CELL3_FILTER: C83.1 (A), C84.2 (B), R136.2 (B), U26.13 (VC3)
CELL4_FILTER: C84.1 (A), C85.2 (B), R137.2 (B), U26.12 (VC4)
CELL5_FILTER: C85.1 (A), C86.2 (B), R138.2 (B), U26.10 (VC5)
CELL6_FILTER: C86.1 (A), C87.2 (B), R139.2 (B), U26.8 (VC6)
CELL7_FILTER: C87.1 (A), C88.2 (B), R140.2 (B), U26.6 (VC7)
CELL8_FILTER: C88.1 (A), C89.2 (B), R141.2 (B), U26.2 (VC9), U26.4 (VC8)
CELL9_FILTER: C89.1 (A), R142.2 (B), U26.48 (VC10)
GND: C72.2 (B), C90.2 (B), C91.2 (B), C92.2 (B), C93.2 (B), C94.2 (B), C95.2 (B), C96.2 (B), C97.2 (B), C98.2 (B), J12.2, J13.4, Q16.1 (S_DS1_2_3), Q18.2 (E), R116.2 (B), R120.2 (B), R122.2 (B), R123.1 (A), R143.2 (B), R146.2 (B), R147.2 (B), R152.2 (B), R153.2 (B), R154.2 (B), R155.2 (B), R156.2 (B), U26.17 (VSS), U26.18 (SRP), U26.20 (SRN), U26.30 (DFETOFF), U26.33 (RST_SHUT), U27.3 (GND), U28.1 (GND), U29.4 (GND), U29.5 (A2), U29.6 (B2), U30.7 (GND), U31.5 (S2), U31.7 (GND), U31.9 (S3), U31.12 (S4); also elsewhere on the board
MON_ALERT: R144.1 (A), U26.25 (ALERT), U31.2 (S1)
MON_ALERT_HOST: U31.3 (D1); also elsewhere on the board
MON_BAT: C95.1 (A), Q19.3 (C), R148.2 (B), R149.2 (B), U26.47 (BAT)
MON_BREG: Q19.1 (B), U26.37 (BREG)
MON_COMM_PERMIT: U29.7 (Y1), U30.1 (SEL1), U30.4 (SEL2), U30.10 (SEL3), U30.13 (SEL4), U31.1 (SEL1), U31.4 (SEL2), U31.10 (SEL3), U31.13 (SEL4)
MON_CP: R149.1 (A), U26.46 (CP1)
MON_CS: R145.1 (A), U26.29 (CS_N), U30.8 (D3)
MON_CS_HOST: U30.9 (S3); also elsewhere on the board
MON_DCHG: R155.1 (A), U26.31 (DCHG); also elsewhere on the board
MON_DDSG: R156.1 (A), U26.32 (DDSG); also elsewhere on the board
MON_LD: R151.2 (B), U26.41 (LD)
MON_MISO: R143.1 (A), U26.27 (MISO), U27.2 (A)
MON_MISO_HOST: U30.11 (D4); also elsewhere on the board
MON_MISO_SHIFTED: U27.4 (Y), U30.12 (S4)
MON_MOSI: R147.1 (A), U26.28 (MOSI), U30.6 (D2)
MON_MOSI_HOST: U30.5 (S2); also elsewhere on the board
MON_PACK: R150.2 (B), U26.42 (PACK)
MON_POWER_OK: U28.2 (RESET_N), U29.2 (B1)
MON_REG1: C90.1 (A), C91.1 (A), C97.1 (A), R144.2 (B), R145.2 (B), U26.35 (REG1), U27.5 (VCC), U28.3 (VDD)
MON_REG18: C98.1 (A), U26.24 (REG18)
MON_REGIN: C96.1 (A), Q19.2 (E), U26.36 (REGIN)
MON_SCLK: R146.1 (A), U26.26 (SCLK), U30.3 (D1)
MON_SCLK_HOST: U30.2 (S1); also elsewhere on the board
MON_TS1: R152.1 (A), U26.21 (TS1)
MON_TS2: R153.1 (A), U26.22 (TS2)
MON_TS3: R154.1 (A), U26.23 (TS3)
unnamed: C72.1 (A), C73.2 (B), R124.1 (A)
unnamed: C73.1 (A), C74.2 (B), R125.1 (A)
unnamed: C74.1 (A), C75.2 (B), R126.1 (A)
unnamed: C75.1 (A), C76.2 (B), R127.1 (A)
unnamed: C76.1 (A), C77.2 (B), R128.1 (A)
unnamed: C77.1 (A), C78.2 (B), R129.1 (A)
unnamed: C78.1 (A), C79.2 (B), R130.1 (A)
unnamed: C79.1 (A), C80.2 (B), R131.1 (A)
unnamed: F3.1 (A), U25.2 (SWITCHED)
unnamed: F3.2 (B), K4.1 (COM)
RAIL_OK: U29.1 (A1); also elsewhere on the board
TAP0_SOURCE_PROTECTED: J14.1, R123.2 (B), R133.1 (A); also elsewhere on the board
TAP1_SOURCE_PROTECTED: J14.2, R124.2 (B), R134.1 (A); also elsewhere on the board
TAP2_SOURCE_PROTECTED: J14.3, R125.2 (B), R135.1 (A); also elsewhere on the board
TAP3_SOURCE_PROTECTED: J14.4, R126.2 (B), R136.1 (A); also elsewhere on the board
TAP4_SOURCE_PROTECTED: J14.5, R127.2 (B), R137.1 (A); also elsewhere on the board
TAP5_SOURCE_PROTECTED: J14.6, R128.2 (B), R138.1 (A); also elsewhere on the board
TAP6_SOURCE_PROTECTED: J14.7, R129.2 (B), R139.1 (A); also elsewhere on the board
TAP7_SOURCE_PROTECTED: J14.8, R130.2 (B), R140.1 (A); also elsewhere on the board
TAP8_SOURCE_PROTECTED: J14.9, R131.2 (B), R141.1 (A); also elsewhere on the board
TAP9_SOURCE_PROTECTED: J14.10, R132.2 (B), R142.1 (A); also elsewhere on the board
V3V3: C92.1 (A), C93.1 (A), C94.1 (A), U29.8 (VCC), U30.14 (VDD), U31.14 (VDD); also elsewhere on the board

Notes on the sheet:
BQ7694204 SPI/CRC +3.3V REG1 variant. 9S mask: cells1..8 +cell10, VC9 tied to VC8, unused cell9 disabled.
RAM profile firmware/config/bq76942_rev_a.json: COV2.530V, CUV1.2144V, delay~10ms; readback mandatory.
DCHG/DDSG active-LOW fault / healthy-HIGH REG1 permission,0xA6,pull-down. Never use Li-ion defaults.
Host-only balance,2k total input resistance/tap including external1k; slow trim,not full-current balancing.
Open-wire current/settling plus input R must be validated; harness source protection before connector is mandatory.
TMUX SPI/ALERT disconnect if either MCU or REG1 power missing; LV1T34 handles initial1.8V MISO level.
BQ battery-ground SPI is not galvanically isolated; partial-power/backfeed review still mandatory.

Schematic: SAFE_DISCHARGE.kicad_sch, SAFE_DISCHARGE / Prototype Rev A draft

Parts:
D24: BZT52H-C15; D_SOD-123F; MPN BZT52H-C15
D25: red residual-energy indicator / bank-powered; LED_0805_2012Metric; MPN LTST-C170KRKT
J15: KEYED service meter / rated discharge tool connec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
Q20: CSD18540Q5B; VSONP-8-1EP_5x6_P1.27mm; MPN CSD18540Q5B
Q21: BC857B; SOT-23; MPN BC857B,215
Q22: BC847B; SOT-23; MPN BC847B,215
R157: 10k /1W permanent bleed; R_2512_6332Metric; MPN CRCW251210K0FKEG
R158: 100R /HS25 100R F / external chassis mount; MPN HS25 100R F
R159, R161, R162: 10k; R_0805_2012Metric; MPN CRCW080510K0FKEA
R160: 47R; R_0805_2012Metric; MPN CRCW080547R0FKEA
R163: 4.7k; R_0805_2012Metric; MPN CRCW08054K70FKEA
R164: 100k; R_0805_2012Metric; MPN CRCW0805100KFKEA
R165: 22k /0.25W; R_0805_2012Metric; MPN CRCW080522K0FKEA
R166: 100R / HS25 100R F / external service tool; MPN HS25 100R F
U32: Blue Sea6006 / external independent service tool;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; MPN 6006

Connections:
BANK_P_RAW: J15.1, R157.1 (A), R158.1 (A), R165.1 (A), U32.1 (COM); also elsewhere on the board
DUMP_DRAIN: Q20.3 (D_DS5_6_7_8), R158.2 (B); also elsewhere on the board
DUMP_DRIVE: R163.1 (A); also elsewhere on the board
DUMP_GATE: D24.1 (K), Q20.2 (G_DS4), R159.1 (A), R160.2 (B)
DUMP_NPN_C: Q22.3 (C), R162.2 (B)
DUMP_NPN_C_BASE: Q22.1 (B), R163.2 (B), R164.1 (A)
DUMP_PNP_B: Q21.1 (B), R161.1 (A), R162.1 (A)
DUMP_PNP_C: Q21.3 (C), R160.1 (A)
GND: D24.2 (A), D25.1 (K), J15.2, Q20.1 (S_DS1_2_3), Q22.2 (E), R157.2 (B), R159.2 (B), R164.2 (B), R166.2 (B); also elsewhere on the board
unnamed: R166.1 (A), U32.2 (SWITCHED)
RESIDUAL_LED_A: D25.2 (A), R165.2 (B)
V12_DRIVER: Q21.2 (E), R161.2 (B); also elsewhere on the board

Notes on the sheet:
OFF is not safe. LED dark is not safe. Independent meter + all cells + local links + rebound required.
Switched100R initial4.862W, energy up to1752J(+30%); 10k bleed alone ~62h to1V. No guaranteed service time.
Dump unavailable after bus aux loss: permanent bleed + independent service tool remain; do not add unauthorized bank-to-bus supply.
DUMP_DRIVE requires temperature permission; MOSFET-short leaves100R permanently on, resistor thermal review mandatory.

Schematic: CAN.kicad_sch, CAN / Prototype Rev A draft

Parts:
C99: 100nF / 16V X7R; C_0805_2012Metric; MPN C0805C104K5RACTU
J16: robot telemetry CAN / official module CAN separate
J17: selectable termination shunt, fit only at bus end; PinHeader_1x02_P2.54mm_Vertical
R167, R168: 10k; R_0805_2012Metric; MPN CRCW080510K0FKEA
R169: 120R /1%; R_0805_2012Metric; MPN CRCW0805120RFKEA
U33: SN65HVD230DR; SOIC-8_3.9x4.9mm_P1.27mm; MPN SN65HVD230DR

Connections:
CAN_H: J16.1, R169.1 (A), U33.7 (CANH); also elsewhere on the board
CAN_L: J16.2, J17.2, U33.6 (CANL); also elsewhere on the board
CAN_RX: U33.4 (R); also elsewhere on the board
CAN_STANDBY: R168.1 (A), U33.8 (RS); also elsewhere on the board
CAN_TERM: J17.1, R169.2 (B)
CAN_TX: R167.1 (A), U33.1 (D); also elsewhere on the board
GND: C99.2 (B), J16.3, U33.2 (GND); also elsewhere on the board
V3V3: C99.1 (A), R167.2 (B), R168.2 (B), U33.3 (VCC); also elsewhere on the board

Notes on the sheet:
Classic CAN initial protocol, bitrate/ID/timeouts TBD. CAN comm must not bypass official cutoff.
CAN powered-off impedance/common-mode protection and external power through UART/SWD/taps require validation.

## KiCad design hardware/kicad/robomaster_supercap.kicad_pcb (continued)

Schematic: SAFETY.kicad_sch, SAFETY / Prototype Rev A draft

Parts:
C100, C101, C102, C103, C104, C105, C106, C107, C108, C109, C110, C111, C112, C113, C114, C115, C116, C117, C118, C119, C120, C121, C122, C123, C124, C125, C126, C127, C128, C129, C133, C134, C135, C136, C137, C138, C139, C140: 100nF / 16V X7R; C_0805_2012Metric; MPN C0805C104K5RACTU
C130, C131, C132: 1nF /50V; C_0805_2012Metric; MPN C0805C102J1GACTU
J18: latched fault diagnostic output; PinHeader_1x02_P2.54mm_Vertical
R170: 58.7k /1%; R_0805_2012Metric; MPN CRCW080558K7FKEA
R171, R173: 10k /PROVISIONAL; R_0805_2012Metric; MPN CRCW080510K0FKEA
R172: 35.7k /1%; R_0805_2012Metric; MPN CRCW080535K7FKEA
R174: 35.7k; R_0805_2012Metric; MPN CRCW080535K7FKEA
R175: 10k / IL12.035A PROVISIONAL; R_0805_2012Metric; MPN CRCW080510K0FKEA
R176, R178, R179, R180, R181, R182, R183, R184, R185, R186, R188, R190, R193, R202, R204, R206, R208: 10k; R_0805_2012Metric; MPN CRCW080510K0FKEA
R177: 10k / preset timeout; verify SET1 table; R_0805_2012Metric; MPN CRCW080510K0FKEA
R187, R189: 1.74k /PROVISIONAL; R_0805_2012Metric; MPN CRCW08051K74FKEA
R191: 3.01k /PROVISIONAL; R_0805_2012Metric; MPN CRCW08053K01FKEA
R192: 1k; R_0805_2012Metric; MPN CRCW08051K00FKEA
R194: 2.2k; R_0805_2012Metric; MPN CRCW08052K20FKEA
R195: 221k /1%; R_0805_2012Metric; MPN CRCW0805221KFKEA
R196, R198, R200: 10k /1%; R_0805_2012Metric; MPN CRCW080510K0FKEA
R197: 154k /1%; R_0805_2012Metric; MPN CRCW0805154KFKEA
R199: 172k /1%; R_0805_2012Metric; MPN CRCW0805172KFKEA
R201: 80.6k; R_0805_2012Metric; MPN CRCW080580K6FKEA
R203, R207: 100k; R_0805_2012Metric; MPN CRCW0805100KFKEA
R205: 78.7k; R_0805_2012Metric; MPN CRCW080578K7FKEA
U34, U35, U38, U56, U58, U60, U65, U66, U69, U71: TLV3202DGKR; VSSOP-8_3x3mm_P0.65mm; MPN TLV3202DGKR
U36, U37, U39, U40, U43, U44, U45, U46, U48, U49, U50, U51, U52, U53, U54, U55, U57, U59, U61, U62, U63, U67, U68, U70, U72: SN74LVC2G08DCUR; VSSOP-8_2.3x2mm_P0.5mm; MPN SN74LVC2G08DCUR
U41: TPS3839K33DBZR; SOT-23; MPN TPS3839K33DBZR
U42: TPS3431SDRBR; VSON-8-1EP_3x3mm_P0.65mm_EP1.65x2.4mm; MPN TPS3431SDRBR
U47: SN74LVC1G74DCUR; VSSOP-8_2.3x2mm_P0.5mm; MPN SN74LVC1G74DCUR
U64: TLV431AIDBZR; SOT-23; MPN TLV431AIDBZR

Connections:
ACTUATOR_12V: R205.1 (A), R207.1 (A); also elsewhere on the board
ACTUATOR_OV_DIV: R207.2 (B), R208.1 (A), U71.6 (INM2)
ACTUATOR_OV_OK: U71.7 (OUT2), U72.2 (B1)
ACTUATOR_UV_DIV: R205.2 (B), R206.1 (A), U71.3 (INP1)
ACTUATOR_UV_OK: U71.1 (OUT1), U72.1 (A1)
ACTUATOR_WINDOW_OK: U72.6 (B2), U72.7 (Y1)
ALL_PROTECT_OK: U68.7 (Y1), U70.5 (A2)
ARM_PULSE: U47.1 (CLK); also elsewhere on the board
ASSEMBLY_PROTECT_OK: U45.5 (A2), U72.3 (Y2)
AUX_OK: U39.3 (Y2), U40.5 (A2)
BANK_OV_DIV: C132.1 (A), R199.2 (B), R200.1 (A), U66.2 (INM1)
BANK_OV_OK: U66.1 (OUT1), U67.6 (B2)
BANK_P_RAW: R199.1 (A); also elsewhere on the board
BANK_TEMP_HI_OK: U60.7 (OUT2), U61.2 (B1)
BANK_TEMP_LO_OK: U60.1 (OUT1), U61.1 (A1)
BANK_THERM_OK: U61.7 (Y1), U62.6 (B2)
BASE_OK: U44.3 (Y2), U45.1 (A1)
BUS_FAST_NEG: U34.6 (INM2); also elsewhere on the board
BUS_FAST_POS: U34.2 (INM1); also elsewhere on the board
BUS_FUSED: R195.1 (A), R197.1 (A); also elsewhere on the board
BUS_ISO_DRIVE: U50.7 (Y1); also elsewhere on the board
BUS_ISO_REQUEST: R180.1 (A), U50.1 (A1); also elsewhere on the board
BUS_LIMIT: R170.2 (B), R171.1 (A), U34.3 (INP1), U34.5 (INP2)
BUS_NEG_OK: U34.7 (OUT2), U36.2 (B1)
BUS_OC_OK: U36.7 (Y1), U37.1 (A1)
BUS_OV_DIV: C130.1 (A), R195.2 (B), R196.1 (A), U65.2 (INM1)
BUS_OV_OK: U65.1 (OUT1), U67.1 (A1)
BUS_POS_OK: U34.1 (OUT1), U36.1 (A1)
BUS_UV_DIV: C131.1 (A), R197.2 (B), R198.1 (A), U65.5 (INP2)
BUS_UV_OK: U65.7 (OUT2), U67.2 (B1)
BUS_WINDOW_OK: U67.5 (A2), U67.7 (Y1)
BYP_BUS_DRIVE: U53.7 (Y1); also elsewhere on the board
BYP_BUS_REQUEST: R183.1 (A), U53.1 (A1); also elsewhere on the board
BYP_CAP_DRIVE: U55.7 (Y1); also elsewhere on the board
BYP_CAP_REQUEST: R185.1 (A), U55.1 (A1); also elsewhere on the board
CAP_FAST_NEG: U35.6 (INM2); also elsewhere on the board
CAP_FAST_POS: U35.2 (INM1); also elsewhere on the board
CAP_ISO_DRIVE: U51.7 (Y1); also elsewhere on the board
CAP_ISO_REQUEST: R181.1 (A), U51.1 (A1); also elsewhere on the board
CAP_LIMIT: R172.2 (B), R173.1 (A), U35.3 (INP1), U35.5 (INP2)
CAP_NEG_OK: U35.7 (OUT2), U36.6 (B2)
CAP_OC_OK: U36.3 (Y2), U37.2 (B1)
CAP_POS_OK: U35.1 (OUT1), U36.5 (A2)
CELLS_HW_OK: U43.7 (Y1), U44.1 (A1)
CELLS_OK: U44.7 (Y1), U45.2 (B1)
CONTACT_PERMIT: U49.7 (Y1), U50.2 (B1), U51.2 (B1), U52.2 (B1), U53.2 (B1), U54.2 (B1), U55.2 (B1)
DRIVER_OV_DIV: R203.2 (B), R204.1 (A), U69.6 (INM2)
DRIVER_OV_OK: U69.7 (OUT2), U70.2 (B1)
DRIVER_PROTECT_OK: U70.3 (Y2), U72.5 (A2)
DRIVER_UV_DIV: R201.2 (B), R202.1 (A), U69.3 (INP1)
DRIVER_UV_OK: U69.1 (OUT1), U70.1 (A1)
DRIVER_WINDOW_OK: U70.6 (B2), U70.7 (Y1)
DUMP_DRIVE: U63.3 (Y2); also elsewhere on the board
DUMP_REQUEST: U63.5 (A2); also elsewhere on the board
FAST_OK: U43.3 (Y2), U44.5 (A2)
FAULT_CLEAR_N: U45.3 (Y2), U46.1 (A1), U48.2 (B1), U48.5 (A2), U49.2 (B1)
FAULT_LATCH_Q: R178.1 (A), U46.6 (B2), U47.5 (Q), U49.1 (A1)
FAULT_LATCH_QN: J18.1, U47.3 (QN)
FET_TEMP_HI_OK: U56.7 (OUT2), U57.2 (B1)
FET_TEMP_LO_OK: U56.1 (OUT1), U57.1 (A1)
FET_THERM_OK: U57.7 (Y1), U62.1 (A1)
GATE_PERMIT: R179.1 (A), U48.7 (Y1); also elsewhere on the board
GND: C100.2 (B), C101.2 (B), C102.2 (B), C103.2 (B), C104.2 (B), C105.2 (B), C106.2 (B), C107.2 (B), C108.2 (B), C109.2 (B), C110.2 (B), C111.2 (B), C112.2 (B), C113.2 (B), C114.2 (B), C115.2 (B), C116.2 (B), C117.2 (B), C118.2 (B), C119.2 (B), C120.2 (B), C121.2 (B), C122.2 (B), C123.2 (B), C124.2 (B), C125.2 (B), C126.2 (B), C127.2 (B), C128.2 (B), C129.2 (B), C130.2 (B), C131.2 (B), C132.2 (B), C133.2 (B), C134.2 (B), C135.2 (B), C136.2 (B), C137.2 (B), C138.2 (B), C139.2 (B), C140.2 (B), J18.2, R171.2 (B), R173.2 (B), R175.2 (B), R178.2 (B), R179.2 (B), R180.2 (B), R181.2 (B), R182.2 (B), R183.2 (B), R184.2 (B), R185.2 (B), R187.2 (B), R189.2 (B), R191.2 (B), R193.2 (B), R196.2 (B), R198.2 (B), R200.2 (B), R202.2 (B), R204.2 (B), R206.2 (B), R208.2 (B), U34.4 (GND), U35.4 (GND), U36.4 (GND), U37.4 (GND), U37.5 (A2), U37.6 (B2), U38.4 (GND), U39.4 (GND), U40.4 (GND), U41.1 (GND), U42.4 (GND), U42.9 (EP), U43.4 (GND), U44.4 (GND), U45.4 (GND), U46.4 (GND), U47.4 (GND), U48.4 (GND), U49.4 (GND), U49.5 (A2), U49.6 (B2), U50.4 (GND), U50.5 (A2), U50.6 (B2), U51.4 (GND), U51.5 (A2), U51.6 (B2), U52.4 (GND), U52.5 (A2), U52.6 (B2), U53.4 (GND), U53.5 (A2), U53.6 (B2), U54.4 (GND), U54.5 (A2), U54.6 (B2), U55.4 (GND), U55.5 (A2), U55.6 (B2), U56.4 (GND), U57.4 (GND), U57.5 (A2), U57.6 (B2), U58.4 (GND), U59.4 (GND), U59.5 (A2), U59.6 (B2), U60.4 (GND), U61.4 (GND), U61.5 (A2), U61.6 (B2), U62.4 (GND), U63.4 (GND), U64.3 (A), U65.4 (GND), U66.4 (GND), U66.5 (INP2), U67.4 (GND), U68.4 (GND), U68.5 (A2), U68.6 (B2), U69.4 (GND), U70.4 (GND), U71.4 (GND), U72.4 (GND); also elsewhere on the board
HW_FAULT_N: U48.3 (Y2); also elsewhere on the board
HW_REF_1V24: R194.2 (B), U64.1 (REF), U64.2 (K), U65.3 (INP1), U65.6 (INM2), U66.3 (INP1), U69.2 (INM1), U69.5 (INP2), U71.2 (INM1), U71.5 (INP2)
IL_FAST_NEG: U38.6 (INM2); also elsewhere on the board
IL_FAST_POS: U38.2 (INM1); also elsewhere on the board
IL_LIMIT: R174.2 (B), R175.1 (A), U38.3 (INP1), U38.5 (INP2)
IL_NEG_OK: U38.7 (OUT2), U39.2 (B1)
IL_OK: U39.7 (Y1), U40.1 (A1)
IL_POS_OK: U38.1 (OUT1), U39.1 (A1)
LATCH_CLEAR_N: U46.7 (Y1), U47.6 (CLR_N)
L_TEMP_HI_OK: U58.7 (OUT2), U59.2 (B1)
L_TEMP_LO_OK: U58.1 (OUT1), U59.1 (A1)
L_THERM_OK: U59.7 (Y1), U62.2 (B1)
MCU_GATE_REQUEST: U46.5 (A2); also elsewhere on the board
MON_CONFIG_VALID: U44.2 (B1); also elsewhere on the board
MON_DCHG: U43.1 (A1); also elsewhere on the board
MON_DDSG: U43.2 (B1); also elsewhere on the board
NRST: U46.2 (B1); also elsewhere on the board
OC_OK: U40.7 (Y1), U43.5 (A2)
PG_DRV: U39.5 (A2); also elsewhere on the board
PG_MCU: U39.6 (B2); also elsewhere on the board
PORT_OC_N: U37.7 (Y1), U40.2 (B1)
POWER_OK: U40.3 (Y2), U43.6 (B2)
POWER_THERM_OK: U62.5 (A2), U62.7 (Y1)
PRE_BUS_DRIVE: U52.7 (Y1); also elsewhere on the board
PRE_BUS_REQUEST: R182.1 (A), U52.1 (A1); also elsewhere on the board
PRE_CAP_DRIVE: U54.7 (Y1); also elsewhere on the board
PRE_CAP_REQUEST: R184.1 (A), U54.1 (A1); also elsewhere on the board
PROTECT_OK: U45.7 (Y1), U63.1 (A1)
RAILS_WINDOW_OK: U67.3 (Y2), U68.2 (B1)
RAIL_OK: U40.6 (B2), U41.2 (RESET_N); also elsewhere on the board
REFEREE_PERMIT: U45.6 (B2); also elsewhere on the board
REQUEST_PERMIT: U46.3 (Y2), U48.1 (A1)
TEMP_BANK_FILTER: U60.3 (INP1), U60.6 (INM2); also elsewhere on the board
TEMP_BANK_LIMIT: R190.2 (B), R191.1 (A), U60.2 (INM1)
TEMP_FET_FILTER: U56.3 (INP1), U56.6 (INM2); also elsewhere on the board
TEMP_FET_LIMIT: R186.2 (B), R187.1 (A), U56.2 (INM1)
TEMP_L_FILTER: U58.3 (INP1), U58.6 (INM2); also elsewhere on the board
TEMP_L_LIMIT: R188.2 (B), R189.1 (A), U58.2 (INM1)
TEMP_OPEN_LIMIT: R192.2 (B), R193.1 (A), U56.5 (INP2), U58.5 (INP2), U60.5 (INP2)
THERM_OK: U62.3 (Y2), U63.2 (B1), U63.6 (B2)
THERM_PROTECT_OK: U63.7 (Y1), U68.1 (A1)
V3V3: C100.1 (A), C101.1 (A), C102.1 (A), C103.1 (A), C104.1 (A), C105.1 (A), C106.1 (A), C107.1 (A), C108.1 (A), C109.1 (A), C110.1 (A), C111.1 (A), C112.1 (A), C113.1 (A), C114.1 (A), C115.1 (A), C116.1 (A), C117.1 (A), C118.1 (A), C119.1 (A), C120.1 (A), C121.1 (A), C122.1 (A), C123.1 (A), C124.1 (A), C125.1 (A), C126.1 (A), C127.1 (A), C128.1 (A), C129.1 (A), C133.1 (A), C134.1 (A), C135.1 (A), C136.1 (A), C137.1 (A), C138.1 (A), C139.1 (A), C140.1 (A), R170.1 (A), R172.1 (A), R174.1 (A), R176.2 (B), R177.2 (B), R186.1 (A), R188.1 (A), R190.1 (A), R192.1 (A), R194.1 (A), U34.8 (VCC), U35.8 (VCC), U36.8 (VCC), U37.8 (VCC), U38.8 (VCC), U39.8 (VCC), U40.8 (VCC), U41.3 (VDD), U42.1 (VDD), U42.3 (EN), U42.5 (SET1), U43.8 (VCC), U44.8 (VCC), U45.8 (VCC), U46.8 (VCC), U47.2 (D), U47.7 (PRE_N), U47.8 (VCC), U48.6 (B2), U48.8 (VCC), U49.8 (VCC), U50.8 (VCC), U51.8 (VCC), U52.8 (VCC), U53.8 (VCC), U54.8 (VCC), U55.8 (VCC), U56.8 (VCC), U57.8 (VCC), U58.8 (VCC), U59.8 (VCC), U60.8 (VCC), U61.8 (VCC), U62.8 (VCC), U63.8 (VCC), U65.8 (VCC), U66.6 (INM2), U66.8 (VCC), U67.8 (VCC), U68.8 (VCC), U69.8 (VCC), U70.8 (VCC), U71.8 (VCC), U72.8 (VCC); also elsewhere on the board
V12_DRIVER: R201.1 (A), R203.1 (A); also elsewhere on the board
WATCHDOG_OK: R176.1 (A), U42.7 (WDO_N), U44.6 (B2)
WD_CWD: R177.1 (A), U42.2 (CWD)
WD_HEARTBEAT: U42.6 (WDI); also elsewhere on the board

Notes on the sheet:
Independent IL INA293 + comparator -> async latch clear -> PWM AND + EN LOW, plus HRTIM FLT1.
Port INA293 pairs + TLV3202 windows + AND. No ADC polling in OC path; maximum delay unverified.
Hardware cell permission requires BQ provisioning; missing/invalid commissioning inhibits startup.
Thermal comparator hot/short/open window; source supply/shared sensor/common shunt failures remain in FMEA.
External contacts release slower than gate kill; coil current/release/fuse coordination require separate review.

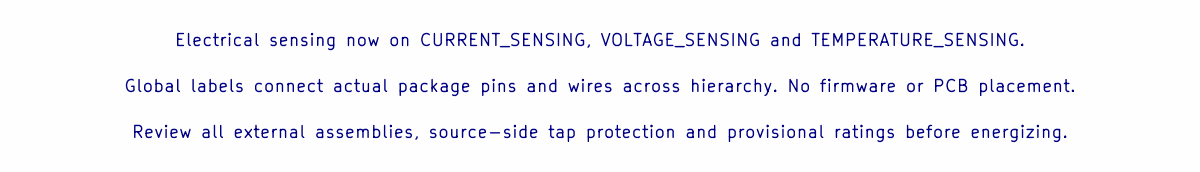
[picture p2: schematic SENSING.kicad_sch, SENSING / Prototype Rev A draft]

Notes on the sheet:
Electrical sensing now on CURRENT_SENSING, VOLTAGE_SENSING and TEMPERATURE_SENSING.
Global labels connect actual package pins and wires across hierarchy. No firmware or PCB placement.
Review all external assemblies, source-side tap protection and provisional ratings before energizing.

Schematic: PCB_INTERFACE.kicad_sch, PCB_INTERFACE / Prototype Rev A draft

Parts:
J19: ACTUATOR_12V / soldered harness with fixture stra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; SolderWire-0.5sqmm_1x01_D0.9mm_OD2.1mm
J20: BANK_P_RAW / soldered harness with fixture strain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; SolderWire-0.5sqmm_1x01_D0.9mm_OD2.1mm
J21: BUS_FUSED / soldered harness with fixture strain 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; SolderWire-2sqmm_1x01_D2mm_OD3.9mm
J22: BUS_ISO_COIL_M / soldered harness with fixture st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; SolderWire-0.5sqmm_1x01_D0.9mm_OD2.1mm
J23: BUS_ISO_FB / soldered harness with fixture strain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; SolderWire-0.5sqmm_1x01_D0.9mm_OD2.1mm
J24: BUS_LINK_IN / soldered harness with fixture strai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; SolderWire-2sqmm_1x01_D2mm_OD3.9mm
J25: BYP_BUS_COIL_M / soldered harness with fixture st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; SolderWire-0.5sqmm_1x01_D0.9mm_OD2.1mm
J26: BYP_BUS_FB / soldered harness with fixture strain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; SolderWire-0.5sqmm_1x01_D0.9mm_OD2.1mm
J27: BYP_CAP_COIL_M / soldered harness with fixture st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; SolderWire-0.5sqmm_1x01_D0.9mm_OD2.1mm
J28: BYP_CAP_FB / soldered harness with fixture strain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; SolderWire-0.5sqmm_1x01_D0.9mm_OD2.1mm
J29: CAN_H / soldered harness with fixture strain reli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; SolderWire-0.5sqmm_1x01_D0.9mm_OD2.1mm
J30: CAN_L / soldered harness with fixture strain reli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; SolderWire-0.5sqmm_1x01_D0.9mm_OD2.1mm
J31: CAP_ISO_COIL_M / soldered harness with fixture st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; SolderWire-0.5sqmm_1x01_D0.9mm_OD2.1mm
J32: CAP_ISO_FB / soldered harness with fixture strain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; SolderWire-0.5sqmm_1x01_D0.9mm_OD2.1mm
J33: CAP_LINK_IN / soldered harness with fixture strai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; SolderWire-2sqmm_1x01_D2mm_OD3.9mm
J34: DUMP_DRAIN / soldered harness with fixture strain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; SolderWire-0.5sqmm_1x01_D0.9mm_OD2.1mm
J35: GND / soldered harness with fixture strain relief; SolderWire-2sqmm_1x01_D2mm_OD3.9mm
J36: PRE_BUS_LED_M / soldered harness with fixture str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; SolderWire-0.5sqmm_1x01_D0.9mm_OD2.1mm
J37: PRE_BUS_LED_P / soldered harness with fixture str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; SolderWire-0.5sqmm_1x01_D0.9mm_OD2.1mm
J38: PRE_CAP_LED_M / soldered harness with fixture str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; SolderWire-0.5sqmm_1x01_D0.9mm_OD2.1mm
J39: PRE_CAP_LED_P / soldered harness with fixture str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; SolderWire-0.5sqmm_1x01_D0.9mm_OD2.1mm
J40: REFEREE_PERMIT / soldered harness with fixture st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; SolderWire-0.5sqmm_1x01_D0.9mm_OD2.1mm
J41: TAP0_SOURCE_PROTECTED / soldered harness with fix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; SolderWire-0.5sqmm_1x01_D0.9mm_OD2.1mm
J42: TAP1_SOURCE_PROTECTED / soldered harness with fix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; SolderWire-0.5sqmm_1x01_D0.9mm_OD2.1mm
J43: TAP2_SOURCE_PROTECTED / soldered harness with fix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; SolderWire-0.5sqmm_1x01_D0.9mm_OD2.1mm
J44: TAP3_SOURCE_PROTECTED / soldered harness with fix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; SolderWire-0.5sqmm_1x01_D0.9mm_OD2.1mm
J45: TAP4_SOURCE_PROTECTED / soldered harness with fix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; SolderWire-0.5sqmm_1x01_D0.9mm_OD2.1mm
J46: TAP5_SOURCE_PROTECTED / soldered harness with fix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; SolderWire-0.5sqmm_1x01_D0.9mm_OD2.1mm
J47: TAP6_SOURCE_PROTECTED / soldered harness with fix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; SolderWire-0.5sqmm_1x01_D0.9mm_OD2.1mm
J48: TAP7_SOURCE_PROTECTED / soldered harness with fix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; SolderWire-0.5sqmm_1x01_D0.9mm_OD2.1mm
J49: TAP8_SOURCE_PROTECTED / soldered harness with fix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; SolderWire-0.5sqmm_1x01_D0.9mm_OD2.1mm
J50: TAP9_SOURCE_PROTECTED / soldered harness with fix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; SolderWire-0.5sqmm_1x01_D0.9mm_OD2.1mm

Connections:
ACTUATOR_12V: J19.1; also elsewhere on the board
BANK_P_RAW: J20.1; also elsewhere on the board
BUS_FUSED: J21.1; also elsewhere on the board
BUS_ISO_COIL_M: J22.1; also elsewhere on the board
BUS_ISO_FB: J23.1; also elsewhere on the board
BUS_LINK_IN: J24.1; also elsewhere on the board
BYP_BUS_COIL_M: J25.1; also elsewhere on the board
BYP_BUS_FB: J26.1; also elsewhere on the board
BYP_CAP_COIL_M: J27.1; also elsewhere on the board
BYP_CAP_FB: J28.1; also elsewhere on the board
CAN_H: J29.1; also elsewhere on the board
CAN_L: J30.1; also elsewhere on the board
CAP_ISO_COIL_M: J31.1; also elsewhere on the board
CAP_ISO_FB: J32.1; also elsewhere on the board
CAP_LINK_IN: J33.1; also elsewhere on the board
DUMP_DRAIN: J34.1; also elsewhere on the board
GND: J35.1; also elsewhere on the board
PRE_BUS_LED_M: J36.1; also elsewhere on the board
PRE_BUS_LED_P: J37.1; also elsewhere on the board
PRE_CAP_LED_M: J38.1; also elsewhere on the board
PRE_CAP_LED_P: J39.1; also elsewhere on the board
REFEREE_PERMIT: J40.1; also elsewhere on the board
TAP0_SOURCE_PROTECTED: J41.1; also elsewhere on the board
TAP1_SOURCE_PROTECTED: J42.1; also elsewhere on the board
TAP2_SOURCE_PROTECTED: J43.1; also elsewhere on the board
TAP3_SOURCE_PROTECTED: J44.1; also elsewhere on the board
TAP4_SOURCE_PROTECTED: J45.1; also elsewhere on the board
TAP5_SOURCE_PROTECTED: J46.1; also elsewhere on the board
TAP6_SOURCE_PROTECTED: J47.1; also elsewhere on the board
TAP7_SOURCE_PROTECTED: J48.1; also elsewhere on the board
TAP8_SOURCE_PROTECTED: J49.1; also elsewhere on the board
TAP9_SOURCE_PROTECTED: J50.1; also elsewhere on the board

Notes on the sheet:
Bench prototype only: wire lands are NOT plug connectors. Harness continuity/polarity inspection mandatory.
External isolation/fuses/precharge/cells remain separate. Each named terminal is a distinct net; do not bridge protection.
2026-10-04 user authorized PCB work without preceding hardware measurement. No fabrication or energizing release.

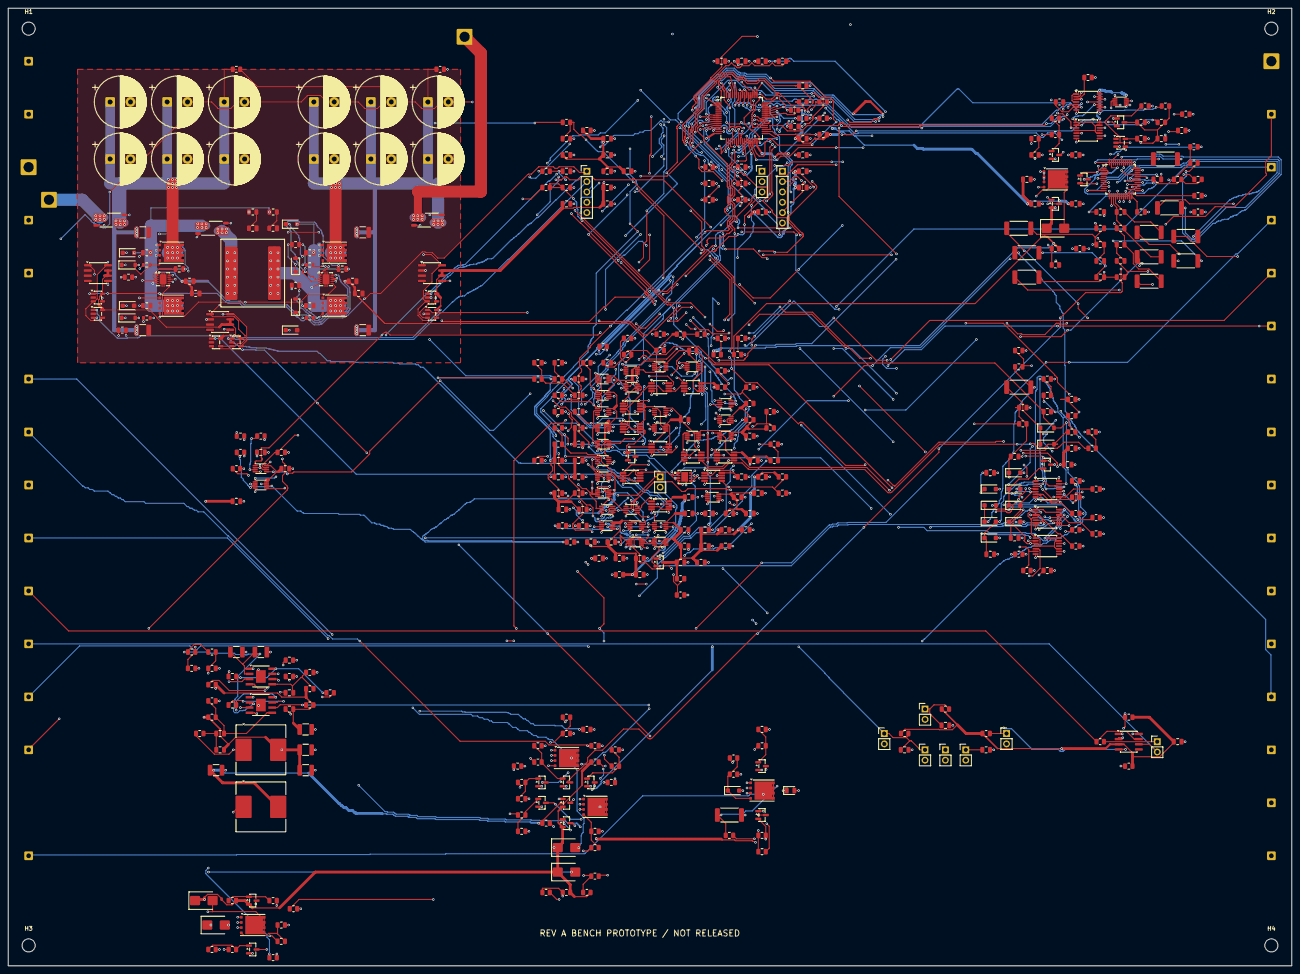
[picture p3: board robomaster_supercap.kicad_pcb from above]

Board: 4 copper layers, 315.0 x 235.0 mm, 485 parts (0 on the bottom side), 285 nets.

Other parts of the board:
H1, H2, H3, H4: MountingHole_3.2mm_M3

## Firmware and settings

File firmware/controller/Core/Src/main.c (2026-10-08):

#include "board.h"
app_t app;

static bq_t monitor;

int main(void) {
    uint32_t previous = 0;
    bq_transport_t transport = {board_spi_transfer, board_delay_us, 0};
    app_init(&app, &rev_a_config, 0);
    /* Factory defaults before DMA/interrupts. */
    board_init();
    app.reset_cause = board_reset_cause();
    bq_init(&monitor, &transport, HAL_GetTick());
    if (app.reset_cause & 24u)
        app_fault(&app, WATCHDOG, HAL_GetTick());
    for (;;) {
        uint32_t now = HAL_GetTick(), faults, key;
        app.hw_fault_clear = HAL_GPIO_ReadPin(GPIOA, GPIO_PIN_12) == GPIO_PIN_SET;
        app.referee_permit = HAL_GPIO_ReadPin(GPIOC, GPIO_PIN_5) == GPIO_PIN_SET;
        app.monitor_alert_asserted = HAL_GPIO_ReadPin(GPIOC, GPIO_PIN_11) == GPIO_PIN_RESET;
        /* ALERT is a request to read cause registers, not proof of a specific fault.
         * Physical DCHG/DDSG/PA12 remain the independent fast shutdown path. */
        if (app.monitor_alert_asserted && monitor.phase == BQ_READY)
            monitor.last_scan_ms = now - 100u;
        board_snapshot(&app.sensors);
        sensors_convert(&app.sensors, &app.calibration);
        key = __get_PRIMASK();
        __disable_irq();
        faults = pending_faults;
        pending_faults = 0;
        __set_PRIMASK(key);
        if (faults)
            app_fault(&app, faults, now);
        /* Faulted monitor is retained for diagnosis. Provisioning never repeats
         * silently and cannot rearm;
               a fresh safe reset/review is needed for BQ failure. */
        bool balancing_allowed = !app.power_session && !app.outputs.gate &&
                                 !app_safe_outputs(&app).dump &&
                                 (app.state == DISARMED || app.state == SERVICE);
        bq_tick(&monitor, now, app.sensors.value[TEMP_BANK_CH], balancing_allowed,
                app.sensors.valid);
        app.monitor = monitor.monitor;
        now = HAL_GetTick();
        board_snapshot(&app.sensors);
        sensors_convert(&app.sensors, &app.calibration);
        key = __get_PRIMASK();
        __disable_irq();
        faults = pending_faults;
        pending_faults = 0;
        __set_PRIMASK(key);
        if (faults)
            app_fault(&app, faults, now);
        board_foreground_io(now);
        if (now - previous >= 1u) {
            app_step(&app, now);
            previous = now;
        }
        board_apply_outputs(&app);
        /* A completed bounded foreground iteration is the heartbeat condition.
         * Fault-latched diagnostic operation is healthy software, not gate permission. */
        board_heartbeat(HAL_GetTick());
    }
}

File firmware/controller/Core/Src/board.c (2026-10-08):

#include "board.h"
#include <math.h>
#include <string.h>
ADC_HandleTypeDef hadc1, hadc2;

DMA_HandleTypeDef hdma1, hdma2;

HRTIM_HandleTypeDef hhrtim1;

FDCAN_HandleTypeDef hfdcan1;

UART_HandleTypeDef huart2;

SPI_HandleTypeDef hspi2;

IWDG_HandleTypeDef hiwdg;

volatile uint32_t pending_faults;

static uint16_t adc1_dma[96] __attribute__((aligned(4)));
static uint16_t adc2_dma[8] __attribute__((aligned(4)));
static uint32_t pwm_period;

static volatile uint16_t latest[ADC_COUNT];

static volatile uint32_t adc1_ms, adc2_ms;

static uint8_t uart_rx_byte;

static uint8_t uart_ring[128];

static volatile uint16_t uart_head, uart_tail;

typedef struct {
    uint16_t id;
    uint8_t data[8];
    uint32_t received_ms;
} can_rx_t;

static can_rx_t can_ring[16];

static volatile uint8_t can_head, can_tail;

static volatile bool outputs_started, arm_was_high, fast_enabled, session_active;
static app_t
    fast_context; /* ISR owns its PI accumulator; foreground publishes only scalar setpoint. */
static volatile float fast_duty_a, fast_duty_b;
volatile uint32_t control_isr_max_cycles;
static volatile bool uart_tx_busy;

/* Nested fault/ADC/CAN interrupts must not lose read-modify-write bits. */
static void fault_pending(uint32_t bits) {
    uint32_t key = __get_PRIMASK();
    __disable_irq();
    pending_faults |= bits;
    __set_PRIMASK(key);
}
static void check(HAL_StatusTypeDef r) {
    if (r != HAL_OK)
        Error_Handler();
}
static void gpio(GPIO_TypeDef *port, uint32_t pins, uint32_t mode, uint32_t pull, uint32_t af) {
    GPIO_InitTypeDef g = {0};
    g.Pin = pins;
    g.Mode = mode;
    g.Pull = pull;
    g.Speed = GPIO_SPEED_FREQ_HIGH;
    g.Alternate = af;
    HAL_GPIO_Init(port, &g);
}
void board_safe_gpio(void) {
    __HAL_RCC_GPIOA_CLK_ENABLE();
    __HAL_RCC_GPIOB_CLK_ENABLE();
    __HAL_RCC_GPIOC_CLK_ENABLE();
    __HAL_RCC_GPIOD_CLK_ENABLE();
    __HAL_RCC_GPIOF_CLK_ENABLE();
    /* ODR latches BEFORE output/AF mode. Hardware pull-downs cover reset/pre-C startup. */
    GPIOA->BSRR = (GPIO_PIN_8 | GPIO_PIN_9 | GPIO_PIN_10 | GPIO_PIN_11) << 16;
    GPIOB->BSRR = (GPIO_PIN_0 | GPIO_PIN_1 | GPIO_PIN_2 | GPIO_PIN_10 | GPIO_PIN_11) << 16;
    GPIOC->BSRR = (GPIO_PIN_6 | GPIO_PIN_7 | GPIO_PIN_8 | GPIO_PIN_9 | GPIO_PIN_10) << 16;
    GPIOD->BSRR = GPIO_PIN_2 << 16;
    GPIOB->BSRR = GPIO_PIN_12;
    GPIOC->BSRR = GPIO_PIN_12;
    /* CS idle;
    CAN standby */
    gpio(GPIOA, GPIO_PIN_8 | GPIO_PIN_9 | GPIO_PIN_10 | GPIO_PIN_11, GPIO_MODE_OUTPUT_PP,
         GPIO_PULLDOWN, 0);
    gpio(GPIOB, GPIO_PIN_0 | GPIO_PIN_1 | GPIO_PIN_2 | GPIO_PIN_10 | GPIO_PIN_11 | GPIO_PIN_12,
         GPIO_MODE_OUTPUT_PP, GPIO_PULLDOWN, 0);
    gpio(GPIOC, GPIO_PIN_6 | GPIO_PIN_7 | GPIO_PIN_8 | GPIO_PIN_9 | GPIO_PIN_10 | GPIO_PIN_12,
         GPIO_MODE_OUTPUT_PP, GPIO_PULLDOWN, 0);
    gpio(GPIOD, GPIO_PIN_2, GPIO_MODE_OUTPUT_PP, GPIO_PULLDOWN, 0);
    gpio(GPIOC, GPIO_PIN_5 | GPIO_PIN_13, GPIO_MODE_INPUT, GPIO_PULLDOWN, 0);
    gpio(GPIOB, GPIO_PIN_4 | GPIO_PIN_5 | GPIO_PIN_6 | GPIO_PIN_7, GPIO_MODE_INPUT, GPIO_PULLDOWN,
         0);
    gpio(GPIOA, GPIO_PIN_15, GPIO_MODE_INPUT, GPIO_PULLDOWN, 0);
    gpio(GPIOC, GPIO_PIN_11, GPIO_MODE_INPUT, GPIO_NOPULL, 0);
    /* external pull-up, active-low alert */
    gpio(GPIOA, GPIO_PIN_12, GPIO_MODE_AF_PP, GPIO_PULLDOWN, GPIO_AF13_HRTIM1);
    gpio(GPIOA, GPIO_PIN_0 | GPIO_PIN_1 | GPIO_PIN_4 | GPIO_PIN_5 | GPIO_PIN_6 | GPIO_PIN_7,
         GPIO_MODE_ANALOG, GPIO_NOPULL, 0);
    gpio(GPIOC,
         GPIO_PIN_0 | GPIO_PIN_1 | GPIO_PIN_2 | GPIO_PIN_3 | GPIO_PIN_4 | GPIO_PIN_14 | GPIO_PIN_15,
         GPIO_MODE_ANALOG, GPIO_NOPULL, 0);
    gpio(GPIOF, GPIO_PIN_0 | GPIO_PIN_1, GPIO_MODE_ANALOG, GPIO_NOPULL, 0);
    /* PA13/14 SWD and PB3 SWO preserved;
        PG10 must remain NRST by option bytes. */
}
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

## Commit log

2026-10-02 hardware: initialize KiCad project
    [CAN.kicad_sch, CONTROLLER.kicad_sch, POWER_INPUT.kicad_sch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]
2026-10-03 simulation: add energy and power budgets with voltage and current limits
2026-10-03 hardware: update existing KiCad architecture and add precharge sheet
    [CAN.kicad_sch, CONTROLLER.kicad_sch, POWER_INPUT.kicad_sch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]
2026-10-03 docs: compare power components and update unresolved safety risks
2026-10-03 docs: propose PCB stack loops thermal and measurement strategy
2026-10-03 docs: define prototype Rev A design envelope
2026-10-03 hardware: implement prototype Rev A electrical schematic
    [AUXILIARY_POWER.kicad_sch, CAN.kicad_sch, CONTROLLER.kicad_sch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]
2026-10-04 docs: select Rev A assembly and cell monitoring profile
2026-10-04 hardware: refine Rev A protection and passive selections
    [AUXILIARY_POWER.kicad_sch, CAN.kicad_sch, CONTROLLER.kicad_sch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]
2026-10-04 hardware: define PCB harness boundary and Kelvin nets
    [AUXILIARY_POWER.kicad_sch, CAN.kicad_sch, CONTROLLER.kicad_sch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]
2026-10-04 hardware: save Rev A placement and partial routing checkpoint
    [robomaster_supercap.kicad_pcb]
2026-10-04 hardware: apply approved fine-pitch clearance rules
2026-10-04 hardware: connect Rev A power paths and add ground fanout
    [robomaster_supercap.kicad_pcb]
2026-10-07 tools: add native-validated PCB routing and cleanup helpers
2026-10-07 hardware: complete Prototype Rev A PCB routing and validation
    [robomaster_supercap.kicad_pcb]
2026-10-08 firmware: implement Rev A STM32 controller and fail-safe framework
    [board.c, interrupts.c]
2026-10-10 docs: link plain-text file references in READMEs
    - Turn the plain-text docs/firmware_validation.md and Drivers/README.md
    mentions into clickable relative links. In firmware/controller/README.md
    the old text was also wrong relative to that file's location.
    - Add the missing space after a semicolon in the root README.
    Documentation only; no firmware, hardware or safety content changed.

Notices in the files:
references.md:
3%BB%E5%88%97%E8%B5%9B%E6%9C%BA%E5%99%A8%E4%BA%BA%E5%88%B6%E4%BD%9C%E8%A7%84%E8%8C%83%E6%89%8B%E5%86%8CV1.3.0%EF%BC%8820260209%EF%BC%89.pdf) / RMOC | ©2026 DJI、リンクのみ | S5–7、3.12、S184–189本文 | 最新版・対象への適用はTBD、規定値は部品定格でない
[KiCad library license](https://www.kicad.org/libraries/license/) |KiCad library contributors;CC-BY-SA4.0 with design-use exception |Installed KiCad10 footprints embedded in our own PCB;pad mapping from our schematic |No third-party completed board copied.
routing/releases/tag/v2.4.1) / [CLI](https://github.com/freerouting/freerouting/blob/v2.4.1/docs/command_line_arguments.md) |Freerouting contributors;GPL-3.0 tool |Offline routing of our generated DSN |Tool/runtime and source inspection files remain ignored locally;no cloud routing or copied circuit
